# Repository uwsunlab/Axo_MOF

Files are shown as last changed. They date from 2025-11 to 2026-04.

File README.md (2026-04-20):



# Reaction-aware control of autonomous batch synthesis

> **Reaction-aware autonomous batch synthesis for ZIF-67 crystallization using robotic liquid handling, in situ UV–Vis spectroscopy, and adaptive Bayesian optimization**

This repository contains the software, analysis workflows, and supporting assets for **Axo**, a modular autonomous platform for solution-phase batch synthesis. The platform integrates robotic reagent delivery, programmable tool changing, cyclic in situ UV–Vis measurements, kinetic model fitting, and reaction-aware Bayesian optimization to co-optimize **what formulation to test** and **how the experiment should be executed**.

---

## 🌟 Key Features

### Reaction-Aware Adaptive Execution
- **Adaptive scheduling**: 
  - **Throughput-prioritized exploration**: 5-vial batch, 15 min measurement interval
  - **Measurement-prioritized refinement**: 2-vial batch, 5 min measurement interval
- **Reaction-aware trigger**: Switch modes automatically when early reaction progress exceeds a threshold
- **Flexible approval modes**: Manual (interactive) or automatic (fully autonomous)
- **State persistence**: Resume interrupted runs from checkpoints

### Automated Synthesis & Characterization
- **Robotic liquid handling**: Precise dispensing with single/dual syringe systems
- **In situ monitoring**: Cyclic UV–Vis spectroscopy integrated into the batch synthesis workflow
- **Autonomous mixing**: Automated mixing and reaction control
- **Programmable multi-vial workflows**: Batch synthesis and cyclic monitoring across multiple reaction vials

### Intelligent Data Analysis
- **Gualtieri kinetic fitting**: Automated MOF growth curve analysis
- **Reaction-progress extraction**: Automatic extraction of extent of reaction `α(t)` and nucleation rate constant `k_n`
- **Gaussian Process modeling**: Uncertainty-aware surrogate models
- **Expected Improvement**: Efficient exploration-exploitation balance

### Production-Ready Engineering
- **Comprehensive logging**: Experiment metadata, synthesis recipes, operation logs, reference spectra, and time-resolved UV–Vis outputs
- **Error handling**: Graceful handling of excluded or failed fits (`no_reaction`, `no_target_feature`)
- **Hardware safety**: Homing checks, collision avoidance, safe Z movements
- **Configuration management**: JSON-based hardware and experiment configs

---

## 📋 Table of Contents

- [System Architecture](#system-architecture)
- [Installation](#installation)
- [Hardware Requirements](#hardware-requirements)
- [Quick Start](#quick-start)
- [Usage](#usage)
- [Project Structure](#project-structure)
- [Documentation](#documentation)
- [Testing](#testing)

---

## 🏗️ System Architecture

The platform is organized into **four main abstraction layers**:

```
┌─────────────────────────────────────────────────────────────┐
│                    Experiment Layer                         │
│  High-level workflows, BO orchestration, kinetic analysis   │
└─────────────────────────────────────────────────────────────┘
                            ↓
┌─────────────────────────────────────────────────────────────┐
│                  Deck & Labware Layer                       │
│     Spatial management, well positions, volume tracking     │
└─────────────────────────────────────────────────────────────┘
                            ↓
┌─────────────────────────────────────────────────────────────┐
│                      Tool Layer                             │
│   Single Syringe, Dual Syringe, Spectrometer, Gripper       │
└─────────────────────────────────────────────────────────────┘
                            ↓
┌─────────────────────────────────────────────────────────────┐
│                    Machine Layer                            │
│    G-code execution, motion control, hardware interface     │
└─────────────────────────────────────────────────────────────┘
```

**Communication**: HTTP REST API to Duet 3 controller (RepRapFirmware)

---

## 💻 Installation

### Prerequisites

- **Python**: 3.8 or higher
- **Hardware**: Modified Jubilee 3D printer with Duet 3 controller
- **Network**: Local network connection to Jubilee (default: 192.168.1.2)

### Dependencies

Install required Python packages:

```bash
# Core scientific computing
pip install numpy scipy scikit-learn pandas

# Visualization
pip install matplotlib python-ternary

# Optional: Jupyter for notebook interface
pip install jupyter
```

### Setup

1. **Clone the repository**:
   ```bash
   git clone <repository-url>
   cd Axo_MOF
   ```

2. **Install the package** (optional, for development):
   ```bash
   cd Code
   pip install -e .
   ```

3. **Verify installation**:
   ```bash
   python -c "import numpy, scipy, sklearn, matplotlib; print('✓ Dependencies OK')"
   ```

---

## 🔧 Hardware Requirements

### Core Platform
- **Jubilee 3D printer** (modified for lab automation)
- **Duet 3 controller** running RepRapFirmware
- **Network connection** (Ethernet or WiFi)

### Tools (mounted on tool changer)
- **T0**: Single syringe (precise liquid dispensing)
- **T2**: Dual syringe (parallel dispensing)
- **T3**: Ocean Optics spectrometer (UV-Vis, 200-1100 nm)
- **T4**: Vacuum gripper (lid handling)

### Labware
- SLAS-standard microplates (6-slot deck)
- 10-well sample vials (14 mL capacity)
- 2-well precursor reservoirs (60 mL capacity)

---

## 🚀 Quick Start

### Option 1: Command-Line Interface (Recommended for Production)

**optimization with manual approval:**
```bash
cd Code
python run_bo_optimization.py --new --approval-mode manual
```

**Fully autonomous (automatic mode transitions):**
```bash
python run_bo_optimization.py --new --approval-mode automatic
```

**traditional BO:**
```bash
python run_bo_optimization.py --new --phases single --batch-size 5 --max-iterations 20
```

**Resume interrupted run:**
```bash
python run_bo_optimization.py --resume
```

### Option 2: Jupyter Notebook (Recommended for Interactive Use)

```bash
cd Code
jupyter notebook multi_phase_bo_orchestration.ipynb
```

The notebook provides:
- Step-by-step hardware initialization
- Interactive configuration
- In situ monitoring
- Built-in visualization and analysis

---

## 📖 Usage

### Adaptive Execution

The system runs through **two optimization modes**:

| Mode | Goal | Batch Size | Measurement Interval (min) | Exploration (xi) | 
|---|---|---|---|---|
| **Exploration** | Broad screening | 5 | 15 | 0.01 | 
| **Refinement** | Focused optimization | 2 | 5 | 0.01 | 

**Mode Transition Criteria:**
- Switch from exploration to refinement when any sample reaches early reaction progress `α(t1) > 0.5`

### Command-Line Arguments

```bash
python run_bo_optimization.py [OPTIONS]

Required (choose one):
  --new                   Start new optimization
  --resume                Resume from saved state

Multi-Phase Options:
  --approval-mode {manual,automatic}
                          Phase transition approval mode (default: manual)
  --phases {multi,single}
                          Phase configuration (default: multi)

Single-Phase Options (ignored in multi-phase):
  --batch-size N          Experiments per batch (default: 5)
  --max-iterations N      Maximum iterations (default: 20)

General Options:
  --output-dir DIR        Output directory (default: optimization_results)
  --operator NAME         Operator name (default: Operator)
```

### Workflow Example

```bash
# Start new multi-phase optimization with manual approval
python run_bo_optimization.py --new --approval-mode manual --operator "Alice"

# System will:
# 1. Generate 5 initial samples (maximin sampling)
# 2. Prompt you to load vials
# 3. Run automated synthesis + spectroscopy
# 4. Extract kinetic descriptors using Gualtieri fitting
# 5. Update GP model
# 6. Enter exploration phase (5 vials, 15 min interval)
# 7. Prompt for approval when criteria met
# 8. Transition to refinement phase (2 vials, 5 min interval)
# 9. Converge and report optimal conditions
```

### Jupyter Notebook Workflow

See [multi_phase_bo_orchestration.ipynb](Code/multi_phase_bo_orchestration.ipynb) for:
- Interactive hardware setup and calibration
- Configuration with validation
- Progress visualization
- Post-optimization analysis and plotting

---

## 📁 Project Structure

```
Axo_MOF/
├── Code/
│   ├── src/
│   │   └── science_jubilee/
│   │       ├── Machine.py              # Core machine controller
│   │       ├── Experiment.py           # High-level experiment workflows
│   │       ├── tools/                  # Tool implementations
│   │       │   ├── Syringe.py
│   │       │   ├── Double_Syringe.py
│   │       │   ├── Oceandirect_axo.py  # Spectrometer
│   │       │   └── Vacuum_Gripper.py
│   │       ├── labware/                # Labware definitions
│   │       ├── decks/                  # Deck configurations
│   │       ├── analysis/               # Data analysis modules
│   │       │   └── gualtieri.py        # Kinetic fitting
│   │       ├── optimization/           # Bayesian optimization
│   │       │   ├── bayesian.py         # GP modeling, EI
│   │       │   ├── sampling.py         # Initial sampling
│   │       │   ├── phase_config.py     # Phase definitions
│   │       │   ├── phase_manager.py    # Phase transitions
│   │       │   ├── orchestrator.py     # Main BO loop
│   │       │   ├── convergence.py      # Stopping criteria
│   │       │   ├── notifications.py    # User interface
│   │       │   └── logging_config.py   # Structured logging
│   │       └── utils/
│   │           └── synthesis_plan.py   # Experiment plan generation
│   │
│   ├── bayesian.ipynb                  # BO analysis and visualization
│   ├── draft_synthesis_plan.json       # Example synthesis-plan configuration
│   ├── gualtieri.ipynb                 # Kinetic fitting workflow
│   ├── mof_synthesis.ipynb             # Manual synthesis workflows
│   ├── multi_phase_bo_orchestration.ipynb  # Interactive orchestration notebook
│   ├── run_bo_optimization.py          # Main CLI entry point
│   └── sampling.ipynb                  # Initial/maximin sampling workflow
|
├── Dataset/                            # Experimental data
│   └── {experiment_name}_{timestamp}/
│       ├── references/                # Background/reference spectra
│       ├── spectra/                   # Time-resolved spectral outputs
│       ├── experiment_metadata.json   # Experiment-level metadata
│       ├── mof_recipes.json           # Per-vial synthesis recipes
│       └── operations_log.txt         # Chronological robotic execution log
│
└── README.md                           # This file
```

---

## 📚 Documentation

### For Users
- **[Quick Start Notebook](Code/multi_phase_bo_orchestration.ipynb)**: Interactive guide for running experiments

### Example Notebooks
- **[mof_synthesis.ipynb](Code/mof_synthesis.ipynb)**: Manual synthesis workflows and calibration
- **[bayesian.ipynb](Code/bayesian.ipynb)**: BO analysis and visualization
- **[gualtieri.ipynb](Code/gualtieri.ipynb)**: Spectral analysis and kinetic fitting
- **[sampling.ipynb](Code/sampling.ipynb)**: Initial space-filling / maximin sampling
---

## 🧪 Testing

1. **Dry run** (test communication, no synthesis):
   ```bash
   python run_bo_optimization.py --new --phases single --batch-size 1 --max-iterations 1
   # Press Ctrl+C when prompted to load vials
   ```

2. **Single iteration** (full workflow test):
   ```bash
   python run_bo_optimization.py --new --phases single --batch-size 2 --max-iterations 1
   ```

3. **Multi-phase test**:
   ```bash
   python run_bo_optimization.py --new --approval-mode manual
   ```

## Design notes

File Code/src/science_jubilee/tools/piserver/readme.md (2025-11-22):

This is a simple camera server to run on a raspberry pi to basically make a webcam. This lets you ping the pi for a picture when you are ready

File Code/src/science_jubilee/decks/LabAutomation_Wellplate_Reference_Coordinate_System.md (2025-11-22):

# Deck Orientation & Jubilee Coordinate System

 The Laboratory Automation Bed Plate and well plates are oriented as follows:

Lab Automation Bed plate & Wellplate Coordinate System

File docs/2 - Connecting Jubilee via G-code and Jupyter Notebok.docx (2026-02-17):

# Jubilee 3D Documentation (Part 2)

Prepared by: Arthur Chong

Date: 05/20/2025

This document is the second part of a multi-part guide that provides step-by-step instructions on how to connect a Jubilee 3D printer using G-Code and Jupyter Notebook.

## Connecting Jubilee via G-Code

Once the IP address has been successfully configured for the Jubilee, you can connect to it via a web interface that allows G-Code control.

### 1. Accessing the G-Code Web Interface

1. Launch your preferred browser (e.g., Google Chrome). The IP address assigned to Jubilee during setup should be saved in your browser history or bookmarks.
2. Type in the IP address you assigned to the Jubilee during setup.
3. You will be directed to the Duet Web Control interface.

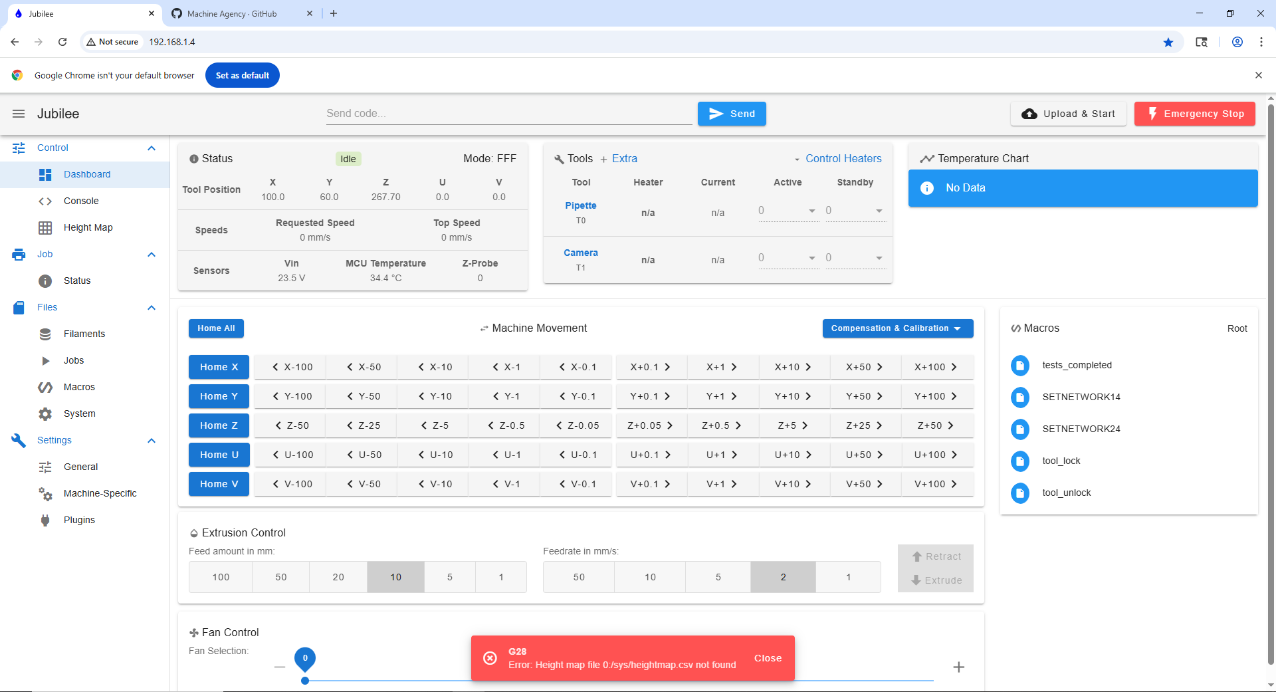
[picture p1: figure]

a

b

c

d

This interface allows you to send G-Code commands directly to the printer, monitor status, control temperatures, move motors, and more.

#### Getting Started Safely

1. Turn on the Jubilee:

Use the external power switch located on the side of the Jubilee frame. (Picture of the switch)

2. Home the Axes:

Before moving the robotic platform, always click "Home All" in the Duet interface to home the X, Y, Z, and U axes.

(U will home first, Y , x , and z)

3. Manual Control:

After homing, you may freely move any of the axes using the interface sliders or input boxes based on your needs.

(Keep in mind of the homing axis)

4. Emergency Stop:

In case of an unexpected issue or malfunction, click the red "Emergency Stop" button in the top-right corner of the screen.

⚠️ This will immediately halt all motion and processes.

u

### 2. Key Interface Components (Figure Description)

a. Side Menu: Access core sections including Jobs, G-Code Files, Machine Control, and Settings.
b. G-Code Console: Send manual commands to operate the printer or test routines.
c. Machine Status Panel: View real-time temperature readings, current axis positions, feed rates, and job status.
d. Motion Control Panel: Move the bed plate and tool holder by manually changing the X, Y, Z, and U axis positions.

### 3. Side Menu – File Options Overview (Additional Information)

Within the side menu of the Duet Web Control interface, the "Files" section is divided into several important tabs:

##### 1. Jobs

- Contains G-code files that can be executed as print or automation jobs.
- You can upload, delete, or organize files for direct execution on the machine.
- Pre-made Job Templates Science Jubilee provides a collection of pre-configured G-code templates used for:
  - Tool pickup
  - Tool change

These templates are useful starting points for setting up your own automated workflows.
👉 Science Jubilee G-code Templates (GitHub) (https://github.com/machineagency/science-jubilee/tree/main/src/science_jubilee/calibration/templates)

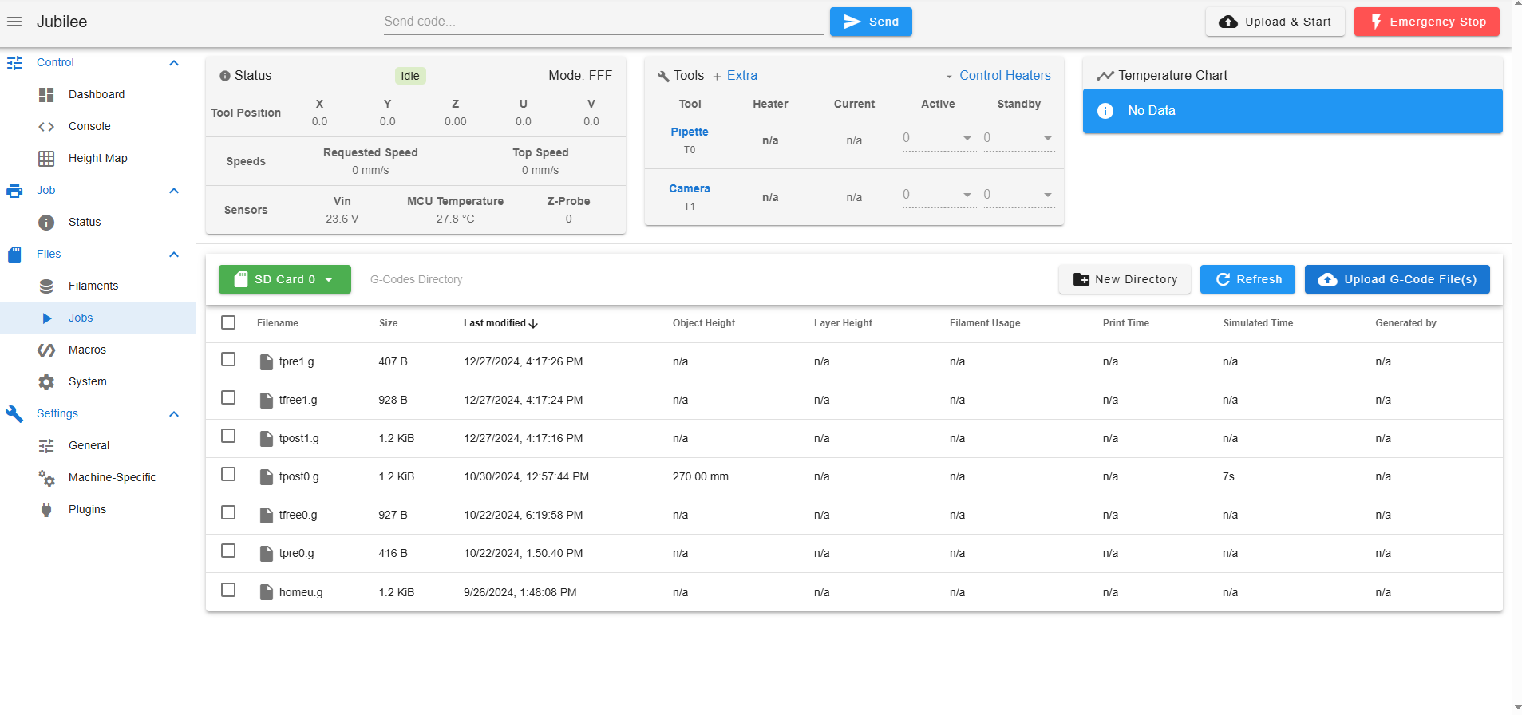
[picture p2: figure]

##### 2. Macros

- Stores reusable G-code scripts for common tasks (e.g., tool lock, tool unlocking).
- Useful for automating frequent commands or procedures.
- Pre-configured Macro Files The Machine Agency has provided a collection of. g macro files specifically designed for Jubilee with Duet 3. 👉 Duet3 Macros – Jubilee GitHub Repository (https://github.com/machineagency/jubilee/tree/main/software/duet_config_files/duet3/macros)

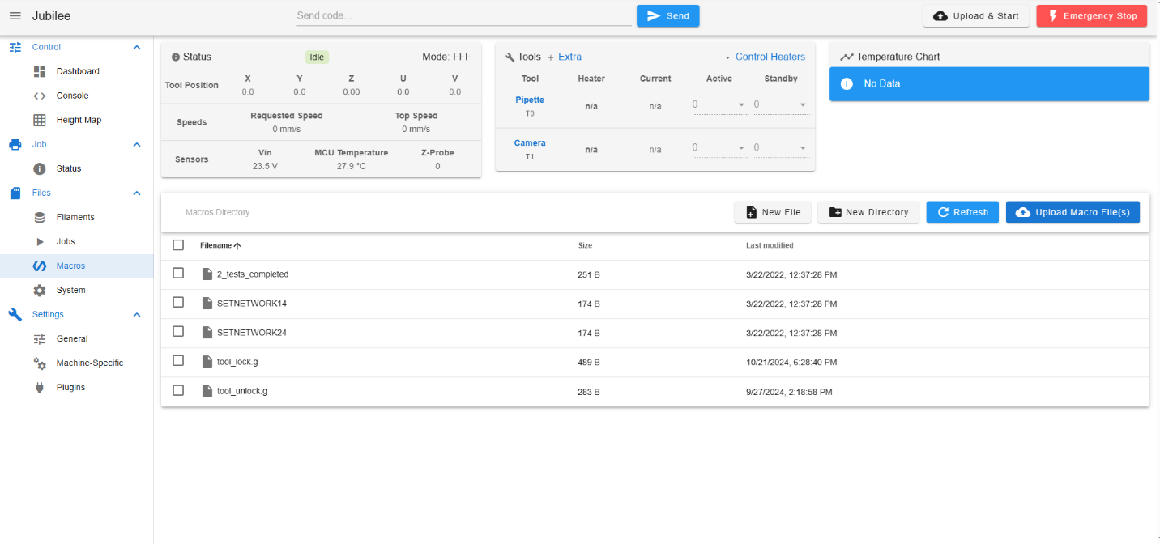
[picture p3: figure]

##### 3. System

- Holds configuration files such as:
  - config.g (main printer configuration)
  - Homex.g, homey.g, homez.g, etc. – Homing sequences for each axis.
- Changes to these files affect machine behavior and should be edited carefully based on your system.

⚠️ Note: Any changes to these files directly affect how the Jubilee operates. Be sure to back up the original files and test carefully after making modifications.

- Reference Configuration Files The Machine Agency provides a complete set of example configuration files for a Duet 3-based Jubilee setup. These can be used as a baseline and tailored to your lab’s hardware.

👉 System Config Files – Duet3 (Jubilee GitHub) (https://github.com/machineagency/jubilee/tree/main/software/duet_config_files/duet3/sys)

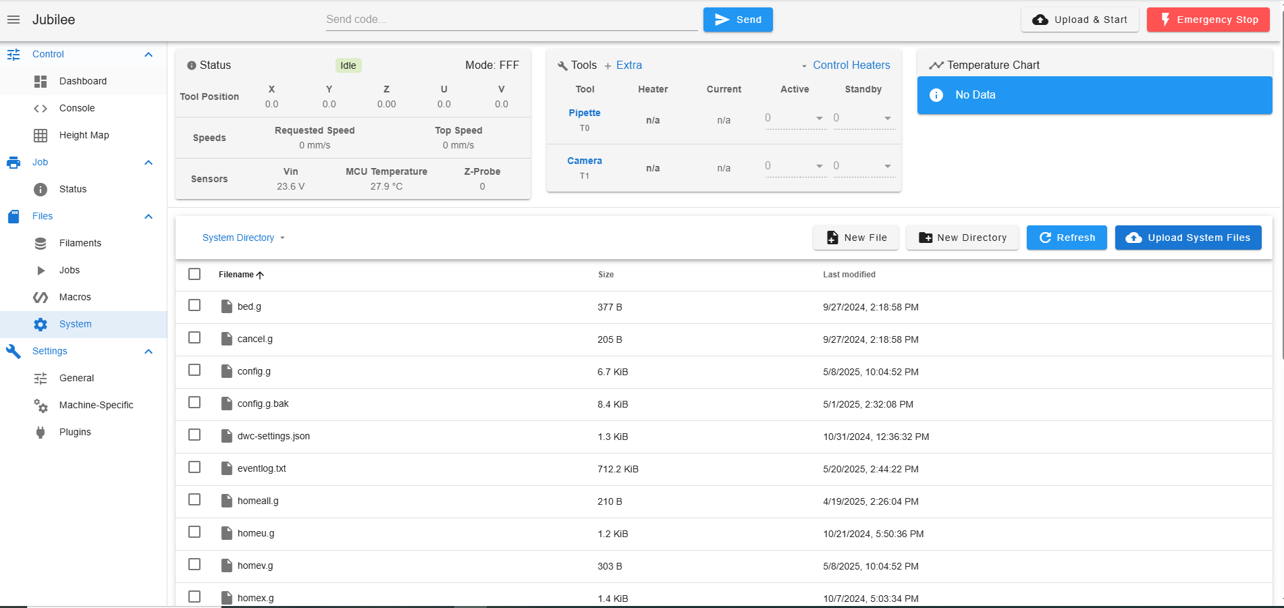
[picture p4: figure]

##### 4. Machine-Specific

- Displays information specific to the hardware setup.
- Here you can view:
  - The type of Duet board in use (e.g., Duet 3 Mini, Duet 2 WiFi)
  - Firmware version and connected expansion boards

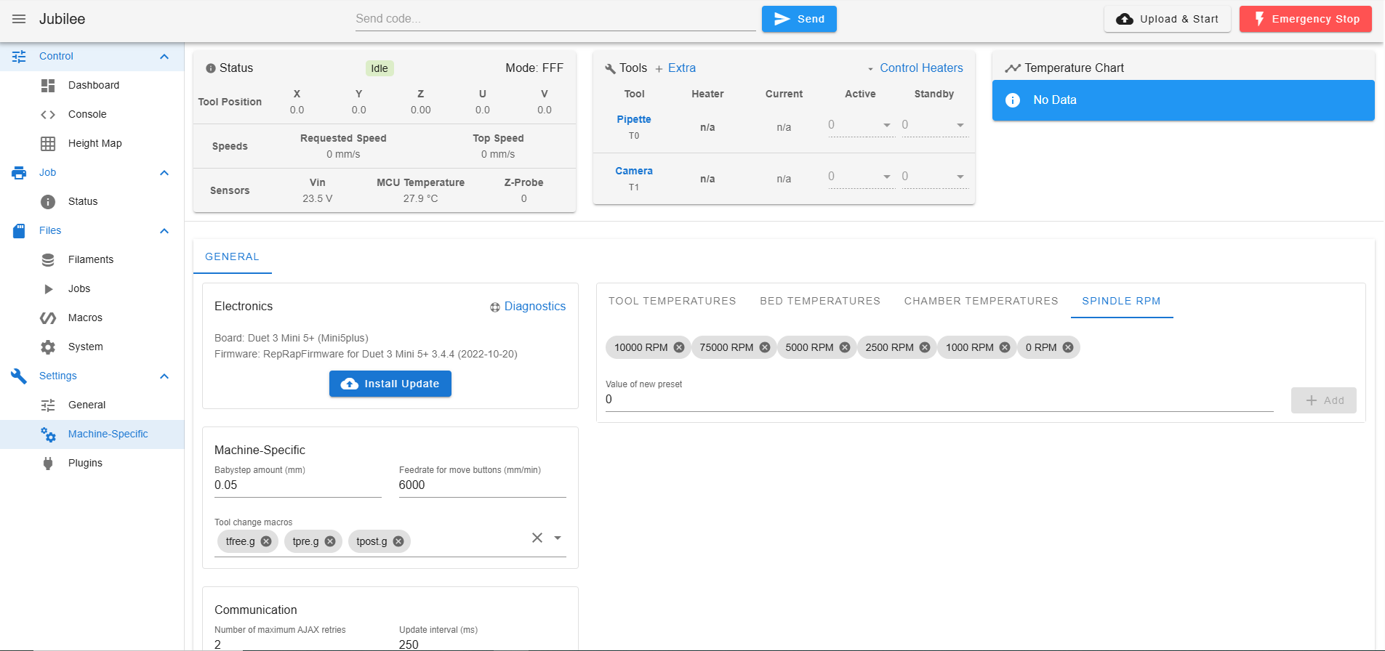
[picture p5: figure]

#### 📚 Additional Resources

To learn more about G-Code and how it's used in Jubilee, refer to the following documentation:
🔗 G-Code Primer
👉 https://science-jubilee.readthedocs.io/en/latest/getting_started/primer.html

For provisioning the board and initial connection setup:
🔗 New User Guide
👉 https://science-jubilee.readthedocs.io/en/latest/getting_started/new_user_guide.html

Duet3D also provides an excellent guide on connecting to your Duet board:
🔗 Duet3D – Getting Connected
👉 https://docs.duet3d.com/How_to_guides/Getting_connected/Getting_connected_to_your_Duet

Senbd code

Config gile change – tool manupulation

## Automating Jubilee with Jupyter Notebook

After uploading all the necessary files into the Macros and System folders, users can connect to Jubilee programmatically using Jupyter Notebooks. This enables full automation of experiments and workflows.

Through Jupyter, users can:

- Send G-code commands via Python
- Control tool pickup and change sequences
- Coordinate movement and actions on the Lab Automation Deck
- Run complex experimental protocols with real-time feedback

### 1. Getting Started Resources

To begin using Jubilee with Jupyter Notebooks, refer to the following tutorials:

1. 👉 Intro to the Machine Driver (https://science-jubilee.readthedocs.io/en/latest/getting_started/machine_intro.html) Learn about the software stack behind Jubilee automation.
2. 👉 Lab Automation Deck Guide (https://science-jubilee.readthedocs.io/en/latest/getting_started/deck_guide.html) Understand how the deck is structured and how to control lab hardware in a programmable way.

### 2. API Reference

The Science Jubilee project provides a fully documented API that outlines the available functions and classes used to interact with and automate the Jubilee 3D printer.

Official API Documentation:
👉 Science Jubilee AutoAPI Reference (https://science-jubilee.readthedocs.io/en/latest/autoapi/index.html)

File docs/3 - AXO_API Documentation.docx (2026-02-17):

AXO API Documentation

System Overview

The AXO platform integrates four modular tools within a 3D printer–like motion framework through a unified control architecture:

- Dual Syringe Pump
- Spectrometer
- Vacuum Gripper
- Single Syringe Pump (or OT2 Pipettes, adapted from the Science-Jubilee project (https://jubilee3d.com/index.php?title=10cc_Syringe_Tool))

Architecture

Each module interfaces through an independent control layer coordinated via:

- G-code: The primary command language governing AXO hardware motion and tool operations.
- JSON Configuration Files: Define labware mappings, tool parameters, and system initialization settings.
- Python Interface: Serves as the orchestration layer, interpreting G-code, managing configurations, and coordinating inter-tool operations.

Table of Contents

## Wiring Diagram

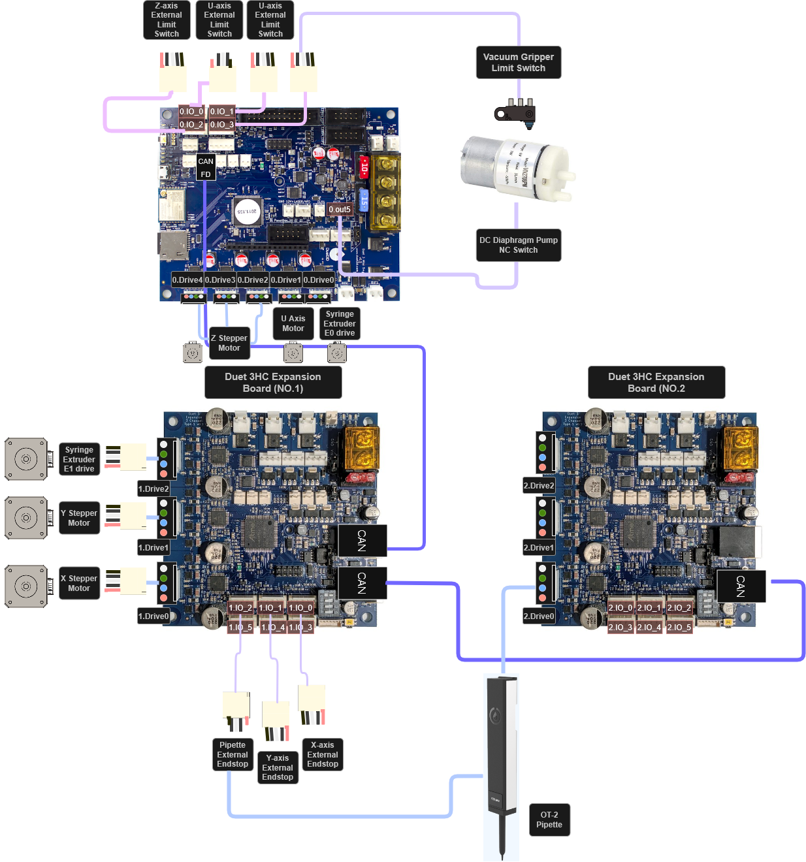
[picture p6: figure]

Note : There is no need to explicitly follow this wiring diagram.

## Dual Syringe Pump

Note: The Dual Syringe Pump API is adapted from the original SyringeExtruder.py provided by the Jubilee collaborators (https://science-jubilee.readthedocs.io/en/latest/building/syringe_tool.html). However, our implementation introduces significant modifications, including automatic refill and aspiration routines. These enhancements eliminate redundant motions and remove the need for tool-changing mechanisms, optimizing the system specifically for materials synthesis workflows.

### Dual Syringe Pump config.g Setup

To configure the Dual Syringe Pump, add the following lines to the config.g file located in the Jubilee/src directory:

—-----------------------------------------------------------------------------------------------------------------

; Dual Syringe Pump Configuration

M584 E0.0:1.2 R0 S1

M569 P1.2 S1 ; Syringe Motor direction (for E1, expansion board)

M569 P0.0 S1 ; Syringe Pump Motor direction (for E0, mainboard)

M906 E{0.85*sqrt(2)*1400}:{0.85*sqrt(2)*1400} ; Syringe Pump: 85% of 1400mA RMS for both E0 and E1

M350 E16:16 I1 ; Enable 16x microstepping for both extruder drives (E0 and E1)

M92 E3200:3200 ; Steps/mm for both drives (E0, E1) of the Double Syringe Pump

M201 E1000:1000 ; Acceleration for both extruder drives (E0, E1)

M203 E1000:1000 ; Maximum speeds for both extruder drives (E0, E1)

M566 E500:500 ; Jerk settings for both extruder drives (E0, E1)

M563 P2 S"Syringe_Pump_r" D0:1 ; Tool 2: Syringe Pump using drives 0 and 1 (E0 and E1)

—--------------------------------------------------------------------------------------------------------------------

### Dual Syringe Pump API (Double_Syringe.py)

### Initialization & Configuration

#### __init__(...)

- Initializes the DoubleSyringe object, sets up tool metadata (like plunger range, conversion factor mm_to_ml), and loads the syringe config from a JSON file.

#### load_config(config: str)

- Loads parameters like min_range, max_range, and mm_to_ml from a config file in /tools/configs.
- Verifies that all required fields are present.

#### post_load()

- Queries the firmware for the tool’s extruder (E) assignments and stores them as self.e0_drive and self.e1_drive (e.g., "E0", "E1").
- Must be called after the tool is loaded into the machine.

#### check_bounds(pos)

- Verifies that a target plunger position pos is within physical limits.
- Throws ToolStateError if movement is unsafe.

### Helper Function for Syringe Motions

In the Dual Syringe Pump, we do not use direct dispensing commands. Instead, the system is designed to automatically refill both syringes by driving them to the end of their respective coordinate ranges.

#### _aspirate(vol, drive, s)

- Moves the specified syringe backwards to aspirate a given volume.
- Checks for overfilling and clamps if needed.
- Returns the actual aspirated volume.
- S : FeedRate (Speed of the motors)

#### _refill(drive, s)

- Moves the plunger to the max position (full) for the given drive, as a full refill.
- Only handles plunger motion—not well positioning.

#### _plunger(drive, delta_mm, s)

- Performs a plunger movement (positive or negative) by a specified distance in relative extrusion mode.
- Switches between relative (M83) and absolute (M82) modes as needed.

### Basic High-Level Syringe Commands

#### refill(drive, refill_loc, s)

- Moves the tool to the refill location and performs a full refill using _refill.

#### aspirate(vol, location, s)

- Moves the tool to a well and aspirates a given volume.
- Uses _aspirate after moving to the coordinates.

#### dispense(vol, location, s)

- Moves the tool to a well and dispenses a given volume.
- Uses _dispense (which seems missing in the code and replaced by _move_channel).

### Drive-Specific Coordinate Helpers

#### _xy_for_drive(drive, loc)

- If the drive is E0, adds offset_x to the x-coordinate. (You can switch your drive on your choice but offsets between the needles should be calculated from the center of each syringe pump)
- Ensures the right(or left) syringe dispenses at the correct x-shifted location.

### Unified Aspirate/Dispense Handler

#### _move_channel(drive, loc, vol, s, dispense, refill_loc)

- Core handler for both aspirate and dispense:
  - Calculates required travel.
  - Handles overfill (for aspirate) or underflow (for dispense) with auto-refill.
  - Moves to correct position and performs plunger motion.
  - Returns volume moved in mL.
- Uses _xy_for_drive() to account for offset_x.

### Wrappers for Dual Channels

To simplify high-level control, the following wrapper functions abstract the direct calls to _move_channel(). These wrappers are designed for clean and readable usage in automation scripts and protocols.

#### aspirate_e0(vol, refill_loc_e, s)

- Aspirates using the E0 drive.

#### dispense_e0(vol, sample_loc_e, refill_loc_e, s)

- Dispenses using E0, with auto-refill if needed.

#### aspirate_e1(vol, refill_loc_v, s)

- Aspirates using E1.

#### dispense_e1(vol, sample_loc_v, refill_loc_v, s)

- Dispenses using E1, with auto-refill if needed.

### Reset Plungers to Zero

#### reset_position(s)

- Moves both syringes to position 0 (fully dispensed)
- Useful to initialize or finalize a run.
- No axis mapping in Syringe Pump, better to reset to position 0.

## Spectrometer

Note: For AXO, the Spectrometer API is built on the proprietary OceanDirect SDK provided by Ocean Optics and serves as a central controller that orchestrates the spectrometer’s interaction with other hardware components. It directly interfaces with the OceanDirect API for real-time spectral acquisition while coordinating machine motion through machine.py and precise well positioning via labware.py. This integration enables synchronized control across devices, allowing the spectrometer to trigger or respond to robotic actions dynamically. Additionally, the API supports flexible data processing routines, making it well-suited for automated, multi-well material characterization workflows.

### Spectrometer config.g Setup

To configure the Spectrometer within the AXO system, add the following line to the config.g file located in the Jubilee/src directory:

—-----------------------------------------------------------------------------------------------------------------

M563 P3 S"Spectrometer"

—--------------------------------------------------------------------------------------------------------------------

### Spectrometer API (Oceandirect_axo.py)

### Initialization & Setup

#### __init__(...)

- Initializes the spectrometer tool, directory structure, and reference spectra.
- Calls open_spectrometer() and _load_references() to auto-connect and recover white/dark spectra.
- Creates:
  - base_dir: root folder for saving data (e.g., "Spectra/")
  - plate_dir: session folder (e.g., "Spectra/20250601/")
  - ref_dir: folder to store dark/white references

### Device Management

#### find_spectrometers()

- Scans for connected Ocean Insight spectrometers.
- Returns a list of available device IDs.

#### open_spectrometer()

- Opens the first available spectrometer and returns it.
- Saves the spectrometer and device ID to self.spectrometer and self.device_id.

#### close_spectrometer()

- Closes the active spectrometer connection cleanly.

### Configuration

#### configure_device(integration_time_us, scans_to_avg, boxcar_width)

- Sets integration time (exposure), scan averaging, and boxcar width (smoothing).

#### lamp_shutter(open)

- Opens/closes the internal shutter, if supported by the spectrometer hardware.

### Measurement & Processing

#### measure_raw_spectrum()

- Returns (wavelengths, intensities) as NumPy arrays.

#### compute_absorbance(sample_vals, dark_vals, white_vals, eps, clip)

- Computes absorbance spectrum from raw data:

A(λ) = -log_10 ((I_(sample) -I_(dark))/(I_(white) -I_(dark) +ε))

- Adds eps to avoid division by zero and optionally clips values.

### Measurement Workflow

#### position_probe(location)

- Moves the stage above the specified well location using Labware._getxyz().
- Saves the current well and location for downstream reference.

#### collect_spectrum(location, elapsed_min, open, save)

- Core function for acquiring a spectrum:
  1. Positions the probe
  2. Opens/closes shutter if needed
  3. Measures raw spectrum
  4. Converts to absorbance
  5. Saves to CSV (if save=True) with time-stamped metadata

### Reference Spectra Handling

Once a reference spectrum has been collected, it can be reused in subsequent measurements to ensure consistent calibration and comparison. The system automatically stores reference spectra in the base_dir/ref directory. You can load and apply a previously captured reference by calling it from this path, eliminating the need to re-capture reference data for every session.

#### set_dark(n_avg)

- Averages n_avg dark readings and stores in ref_dir with a timestamped filename (e.g. dark_20250601_112300.npy).

#### set_white(n_avg)

- Same as above, but for white reference.

#### _load_references()

- Tries to load the most recent timestamped dark_* and white_* files.
- Falls back to dark.npy / white.npy if newer refs not found.

#### _latest_ref(prefix)

- Utility that returns the most recent reference file path based on prefix ("dark" or "white").

### Storage and Metadata

#### set_storage_root(new_root)

- Changes all directory roots to a new base (e.g., switching between experiments).

#### _csv_path(well_id)

- Returns a path like Spectra/20250601/A1.csv.

#### _ensure_file(path, meta)

- Creates the file with a YAML-style metadata header if it doesn't exist.

#### _append_spectrum_csv(well_id, time_min, wl, absorbance, meta)

- Appends a new absorbance column to a .csv file for the specified well, with time (<time_min> min) as column label.
- Preserves YAML-style metadata in the header.

#### read_spectrum_csv(path)

- Reads a saved .csv file and returns both metadata and absorbance DataFrame.

### Global Utility Functions

#### _yaml_header(meta)

- Formats metadata dictionary as a block comment header in YAML-style (for readability and parsing).

#### _parse_header(path)

- Parses and returns the header block as a dictionary + number of lines used.

## Vacuum Gripper

Note: Vacuum Gripper leverages both hardware-level G-code execution and Python-based software abstraction for automated pick-and-place workflows. We implemented the control logic for a vacuum-powered gripping tool. It combines movement planning, GPIO vacuum control, and contact-based probing.

In order to use the Vacuum Gripper you need an NC or NO limit switch and pin it through DUET3D, or else you need to hardcode the picking z-location for appropriate contact.

*To use multiple z-probe, firmware should be updated to 3.5>

*Firmware mismatch of Mainboard(Duet3D mini 5+, Duet3D expansion 3HC) causes improper I/O pin behavior or failure.

### Vacuum Gripper Config.g Setup

To configure the Vacuum Gripper for use with the Duet3D Expansion 3HC board, add the following lines to your config.g file located in the Jubilee/src directory:

—-----------------------------------------------------------------------------------------------------------------

M558 K2 P8 C"^1.io3.in" ; Expansion Board 3HC board number 1 at io3 port, in & ground.

;"Control Point" ; Offset it downwards slightly so we don't smear it along

; the bed while traveling when z=0.

G31 K2 P100 X0 Y0 Z-vacuum_gripper_offsets ; Set the limit switch as the

M563 P4 S"Vacuum_Gripper" ; Define Tool 4 named "Vacuum_Gripper"

—--------------------------------------------------------------------------------------------------------------------

### Vacuum Gripper API

### Initialization

#### __init__(index, name, vacuum_pin, limit_switch_pin)

- Initializes the gripper, storing:
  - vacuum_pin for PWM control (e.g., Duet's M42 P<vacuum_pin> S<pwm>) PWM is the drive voltage to the pump.
  - limit_switch_pin for Z-probe trigger (e.g., Duet's G30 K<switch>)
- Throws error if either pin is not provided

#### grip(location, pwm, retract_z_after_probe)

- Pick up an object at a given location:
  1. Moves in Z safely
  2. Moves to x, y
  3. Starts vacuum (M42 P... S<pwm>)
  4. Lowers Z until limit switch (Z-probe) is triggered via G30 K<switch> S-1
  5. Optionally retracts Z after probing

S-1 means probe but don’t update the Z offset, keeping bed leveling safe

#### drop(location, retract_z_after_probe)

- Release object at a target location:
  1. Moves safely in Z
  2. Moves to x, y
  3. Triggers Z-probe for contact release
  4. Stops vacuum (M42 P... S0)

#### _probe_limit_switch(retract_z_after_probe)

- Sends G-code:
  - G30 K<limit_switch_pin> S-1 to probe Z until the limit switch is triggered
  - move(dz=...) to retract Z afterward

#### pick_and_place(grip, drop, pwm, retract_z_after_probe)

- High-level macro
  1. Calls grip() at the pickup location
  2. Moves to drop() location
  3. Finishes with safe Z retraction

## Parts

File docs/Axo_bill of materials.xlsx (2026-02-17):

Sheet: BOM
Bill of Materials, Axo
Hardware | Axo base
 | Item | Unit price | Quantity | Total | Link
 | Jubilee Motion Platform Kit | $1799.99 | 1 | $1799.99 | https://www.filastruder.com/collections/jubilee/products/jubilee-motion-platform-kit
 | Limit Switches | $1.14 | 5 | $5.70 | https://www.digikey.com/en/products/detail/e-switch/SS0750300F070P1A/3778167
 | 2x5 Female IDC Socket Connector | $6.90 | 1 | $6.90 | https://www.amazon.com/dp/B07W5C4P6Z?skipTwisterOG=2
 | Grey Flat Ribbon Cable In Roll | $9.97 | 1 | $9.97 | https://www.amazon.com/dp/B08435GF42?skipTwisterOG=2
 | M3 Hex Bolt Screw & Flat Head Hex Socket Screws | $11.91 | 1 | $11.91 | https://www.amazon.com/dp/B076ZDXK1W?skipTwisterOG=2
 | Heat Set Insert Tool Kit | $8.99 | 1 | $8.99 | https://www.filastruder.com/products/heat-set-insert-tool-kit?variant=40437399519303
 | Tool Balls for Jubilee (3-pack) | $2.99 | 5 | $14.95 | https://www.filastruder.com/products/tool-balls-for-jubilee-3-pack?_pos=1&_sid=67e00ff4a&_ss=r
 | Wedge Plate for Jubilee (3-pack) | $1.99 | 5 | $9.95 | https://www.filastruder.com/products/wedge-plate-for-jubilee?_pos=2&_sid=67e00ff4a&_ss=r
 | Large Zip Ties | $21.99 | 1 | $21.99 | https://www.amazon.com/dp/B0BZ12PGRT?skipTwisterOG=2
 | Jubilee Aluminum Z Yokes by Mandala Rose Works | $89.99 | 1 | $89.99 | https://www.filastruder.com/collections/jubilee/products/jubilee-aluminum-z-yokes-by-mandala-rose-works
 | Raspberry Pi 5 8GB / Vilros Complete Kit | $159.99 | 1 | $159.99 | https://vilros.com/products/raspberry-pi-5?variant=40082990399582
 | 26 Pins Standard 0.1" 2.54mm Female Sockets | $13.55 | 1 | $13.55 | https://www.amazon.com/dp/B00DR9J5E8?skipTwisterOG=2
 | 40 Pins Standard 0.1" 2.54mm Sockets | $12.85 | 1 | $12.85 | https://www.amazon.com/dp/B00K2NTSJE?skipTwisterOG=2
 | 26 Pins Connector Flat Ribbon Cable | $9.99 | 1 | $9.99 | https://www.amazon.com/dp/B07JPZ9YCF?skipTwisterOG=2
 | 5M GT2 Timing Belt | $10.99 | 1 | $10.99 | https://www.amazon.com/dp/B08R93QQ8Z?skipTwisterOG=2
 | 360 Pcs Allen Head Screws | $7.58 | 1 | $7.58 | https://www.amazon.com/360-Pcs-Allen-Head-Screws/dp/B0D9DCKCNM
 | Socket Head Cap Bolts Screws and Nuts Kit | $11.99 | 1 | $11.99 | https://www.amazon.com/DYWISHKEY-Pieces-Stainless-Socket-Screws/dp/B07VPGQ1RZ?s=industrial
 | M3 spacer (OD 7mm ID 3.2mm) | $9.99 | 1 | $9.99 | https://www.amazon.com/MCMASKE-Plastic-Unthreaded-Assortment-Clearance/dp/B0B7P1JWGT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
 | Total |  |  | $2207.28
Hardware | Tool - Single Syringe
 | Item | Unit price | Quantity | Total | Link
 | Air-Tite™ Sterile Syringes 10 mL, Luer Lock (pack of 100) | $29.70 | 1 | $29.70 | https://www.fishersci.com/shop/products/sterile-syringes-48/14817178
 | BD Hypodermic Needles 23 G, 1.5 in., 0.025 in., Thin (pack of 100) | $27.50 | 1 | $27.50 | https://www.fishersci.com/shop/products/bd-general-use-precisionglide-hypodermic-needles-20/148266C
 | Tr8x2 Lead Screw with T8 Brass Nut | $11.99 | 1 | $11.99 | https://www.amazon.com/150mm%EF%BC%885-9-Inches%EF%BC%89Tr8x2-Thread-Printer-Machine/dp/B0B8RGRYNW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
 | Wedge Plate for Jubilee | $1.99 | 1 | $1.99 | https://www.filastruder.com/products/wedge-plate-for-jubilee?_pos=2&_sid=67e00ff4a&_ss=r
 | GT Timing Belt Pulley | $7.59 | 1 | $7.59 | https://www.amazon.com/gp/product/B07K6BRL4K?th=1
 | 200mm MGN9 Linear Sliding Rail Guide | $16.59 | 1 | $16.59 | https://www.amazon.com/gp/product/B08HYFM5BP
 | 8mm Nonmarring Clamp Collar | $11.99 | 1 | $11.99 | https://www.amazon.com/Shaft-Collar-Aluminum-Thickness-Screws/dp/B0BNZ937MV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
 | Thrust Bearing 8mm Bore | $9.99 | 1 | $9.99 | https://www.amazon.com/HiPicco-Bearings-F8-16M-Miniature-Direction/dp/B0BXY9VF8X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
 | LDO Slim Power Extruder Stepper Pancake Motor | $15.95 | 1 | $15.95 | https://kb-3d.com/store/stepper-motors-servos/66-ldo-slim-power-extruder-stepper-pancake-motor-42sth25-1404mac-1644693835267.html
 | Stepper Motor Heatsink | $6.99 | 1 | $6.99 | https://www.amazon.com/Easycargo-40x40x11mm-Conductive-Thermoelectric-40mmx40mmx11mm/dp/B07D4FVC61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
 | 110t 2gt Belt | $9.89 | 1 | $9.89 | https://www.amazon.com/uxcell-Timing-Closed-110-2GT-6-Printer/dp/B0CN9H34K9
 | Total |  |  | $150.17
Hardware | Tool - Dual Syringe
 | Item | Unit price | Quantity | Total | Link
 | Air-Tite™ Sterile Syringes 10 mL, Luer Lock (pack of 100) | $29.70 | 1 | $29.70 | https://www.fishersci.com/shop/products/sterile-syringes-48/14817178
 | BD Hypodermic Needles 23 G, 1.5 in., 0.025 in., Thin (pack of 100) | $27.50 | 1 | $27.50 | https://www.fishersci.com/shop/products/bd-general-use-precisionglide-hypodermic-needles-20/148266C
 | Tr8x2 Lead Screw with T8 Brass Nut | $11.99 | 1 | $11.99 | https://www.amazon.com/150mm%EF%BC%885-9-Inches%EF%BC%89Tr8x2-Thread-Printer-Machine/dp/B0B8RGRYNW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
 | Wedge Plate for Jubilee | $1.99 | 2 | $3.98 | https://www.filastruder.com/products/wedge-plate-for-jubilee?_pos=2&_sid=67e00ff4a&_ss=r
 | 200mm MGN9 Linear Sliding Rail Guide | $16.59 | 2 | $33.18 | https://www.amazon.com/gp/product/B08HYFM5BP
 | 8mm Nonmarring Clamp Collar | $11.99 | 1 | $11.99 | https://www.amazon.com/Shaft-Collar-Aluminum-Thickness-Screws/dp/B0BNZ937MV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
 | Thrust Bearing 8mm Bore | $9.99 | 1 | $9.99 | https://www.amazon.com/HiPicco-Bearings-F8-16M-Miniature-Direction/dp/B0BXY9VF8X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
 | LDO Slim Power Extruder Stepper Pancake Motor | $15.95 | 1 | $15.95 | https://kb-3d.com/store/stepper-motors-servos/66-ldo-slim-power-extruder-stepper-pancake-motor-42sth25-1404mac-1644693835267.html
 | Stepper Motor Heatsink | $6.99 | 1 | $6.99 | https://www.amazon.com/Easycargo-40x40x11mm-Conductive-Thermoelectric-40mmx40mmx11mm/dp/B07D4FVC61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
 | 16-T 2GT Drive Pulley for 6mm Belt | $6.99 | 1 | $6.99 | https://www.amazon.com/WINSINN-Aluminum-Synchronous-Timing-Printer/dp/B077GMR328
 | 110T, 2GT Timing Belt 6mm Tall | $9.99 | 1 | $9.99 | https://www.amazon.com/PAGOW-Printer-Timing-Closed-Rubber/dp/B088M3V865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
 | 2GT 40T Pulley 8B | $12.99 | 1 | $12.99 | https://a.co/d/4UQ8Md9
 | 110t 2gt Belt | $9.89 | 1 | $9.89 | https://www.amazon.com/uxcell-Timing-Closed-110-2GT-6-Printer/dp/B0CN9H34K9
 | Wire Extender 4pin for LDO Motors | $7.99 | 1 | $7.99 | https://www.amazon.com/Printer-Stepper-Motor-Connector-HX2-54/dp/B0CRDXNWMZ?sp_csd=d2lkZ2V0TmFtZT1zcF9tdGY
 | Total |  |  | $199.12
Hardware | Tool - Vacuum Gripper
 | Item | Unit price | Quantity | Total | Link
 | Vacuum 12V DC Pump | $9.97 | 2 | $19.94 | https://www.amazon.com/dp/B07FGFPKNS?s=hi&sp_csd=d2lkZ2V0TmFtZT1zcF9kZXRhaWxfdGhlbWF0aWM
 | Hose Balbs 3/16" to 1/8" | $6.99 | 1 | $6.99 | https://www.amazon.com/Boeray-5pcs-Brass-Fitting-Adapter/dp/B07DVFG5V5
 | 1/8" Hose Barb Fitting Equal Barbed Y Shaped | $7.99 | 1 | $7.99 | https://www.amazon.com/ANPTGHT-Fitting-plastic-Splicer-Household/dp/B08S6T79JD?sp_csd=d2lkZ2V0TmFtZT1zcF9hdGY
 | Vacuum Suction Cup | $13.99 | 2 | $27.98 | https://www.amazon.com/dp/B0BRKHGQQ5?s=industrial&sp_csd=d2lkZ2V0TmFtZT1zcF9kZXRhaWw
 | 1/8" Silicone Hose 10feet | $8.99 | 1 | $8.99 | https://www.amazon.com/Silicon-CellarBrew-Silicone-Brewing-Winemaking/dp/B08RYFKD53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
 | Wedge Plate for Jubilee | $1.99 | 1 | $1.99 | https://www.filastruder.com/products/wedge-plate-for-jubilee?_pos=2&_sid=67e00ff4a&_ss=r
 | LDO Slim Power Extruder Stepper Pancake Motor | $15.95 | 1 | $15.95 | https://kb-3d.com/store/stepper-motors-servos/66-ldo-slim-power-extruder-stepper-pancake-motor-42sth25-1404mac-1644693835267.html
 | Total |  |  | $71.89
Hardware | Tool - Spectrometer
 | Item | Unit price | Quantity | Total | Link
 | Ocean-HDX UV to NIR Optimized Spectrometer | $7369.00 | 1 | $7369.00 | https://www.oceanoptics.com/spectrometer/ocean-hdx/
 | Tungsten Halogen Light Source HL-2000-LL | $1804.05 | 1 | $1804.05 | https://www.oceanoptics.com/accessories/light-sources/light-sources-product-insight/
 | 300-micron Transmission Dip Probe, UV, PEEK Sleeve | $1214.00 | 1 | $1214.00 | https://www.oceanoptics.com/accessories/fibers-and-probes/transmission-dip-probes/
 | Adjustable Path (2-10 mm) PEEK Tip for TP300-UV/VIS | $392.00 | 1 | $392.00 | https://www.oceanoptics.com/accessories/fibers-and-probes/transmission-dip-probes/
 | Wedge Plate for Jubilee | $1.99 | 1 | $1.99 | https://www.filastruder.com/products/wedge-plate-for-jubilee?_pos=2&_sid=67e00ff4a&_ss=r
 | Total |  |  | $10779.05
 | Chemicals and Labwares
 | Item | Unit price | Quantity | Total | Link
 | Cobalt(II) nitrate hexahydrate, 99%, Thermo Scientific Chemicals | $64.65 | 1 | $64.65 | https://www.fishersci.com/shop/products/cobalt-ii-nitrate-hexahydrate-99-pure-thermo-scientific/AC213091000
 | 2-Methylimidazole, 99%, Thermo Scientific Chemicals | $40.50 | 1 | $40.50 | https://www.fishersci.com/shop/products/2-methylimidazole-99-thermo-scientific/AC127001000
 | Methanol, 4 Liter, HPLC, Thermo Scientific Chemicals | $26.70 | 1 | $26.70 | From Research Stockroom
 | Fisherbrand Glass Shell Vials, 11 mL, pack of 144 | $133.20 | 1 | $133.20 | https://www.fishersci.com/shop/products/51-expansion-short-style-glass-shell-vials-without-closures/0333930F
 | Bottle, Specimen 2 Oz Glass WM | $3.58 | 4 | $14.32 | From Research Stockroom
 | Total |  |  | $279.37

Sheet: Summary
Category |  | Cost (USD)
Axo base |  | 2207
Synthesis | Single syringe | 150
 | Dual syringe | 199
 | Vacuum gripper | 72
Characterization | Spectrometer | 10779
Total |  | 13407

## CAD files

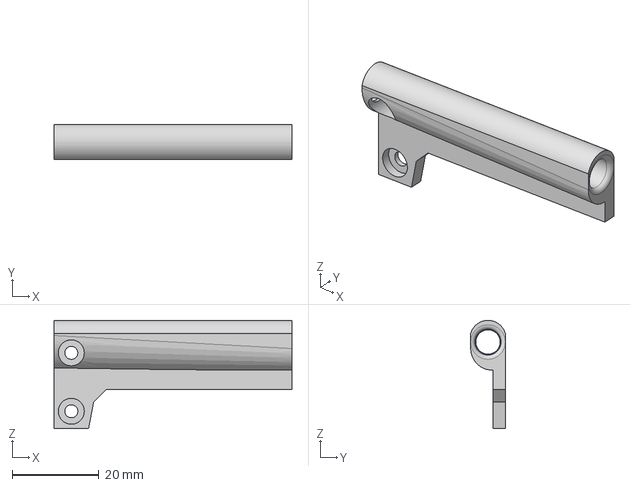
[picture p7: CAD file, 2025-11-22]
CAD/Dual_Syringe/parkin_wing_right v2.step
55.0 x 8.00 x 25.0 mm

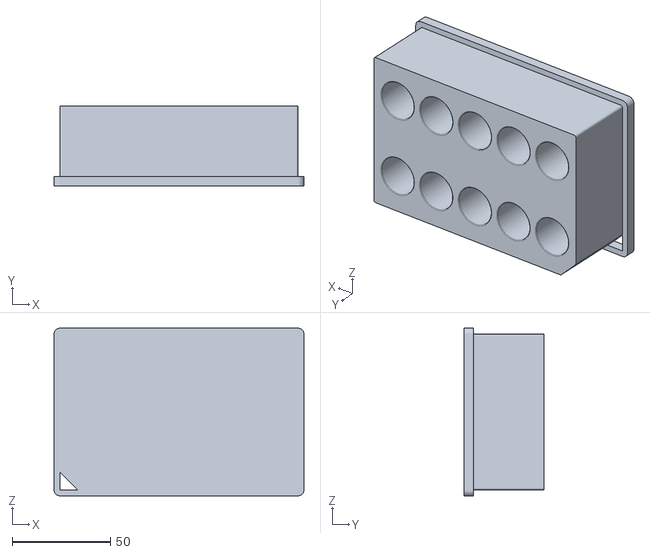
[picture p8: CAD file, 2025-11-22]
CAD/Labwares/UWSUNLAB_10WELLPLATE_11ML_RESERVOIR_INSERT_KIT v2.stl
127.5 x 41.0 x 85.5

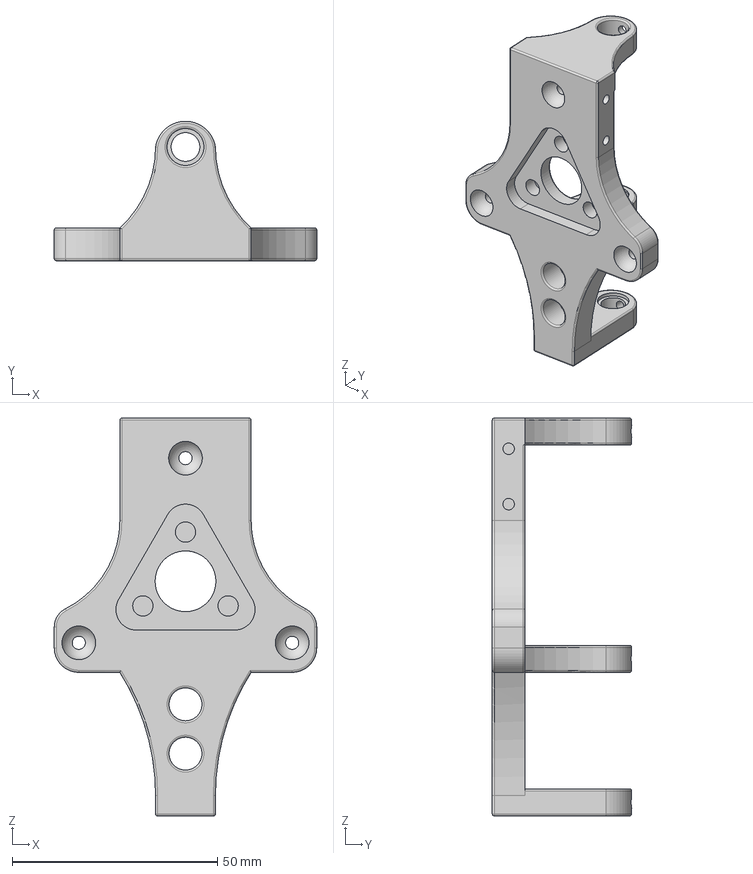
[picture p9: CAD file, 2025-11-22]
CAD/Spectrometer/Spectrometer_tool_base v5.step
64.0 x 34.0 x 97.0 mm

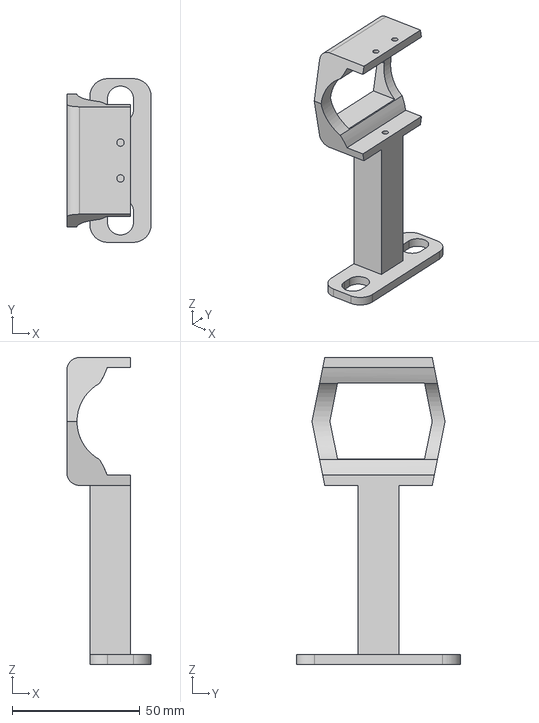
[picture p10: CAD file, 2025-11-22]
CAD/Vacuum_Gripper/vacuum_gripper v10.step
33.0 x 64.0 x 120.0 mm

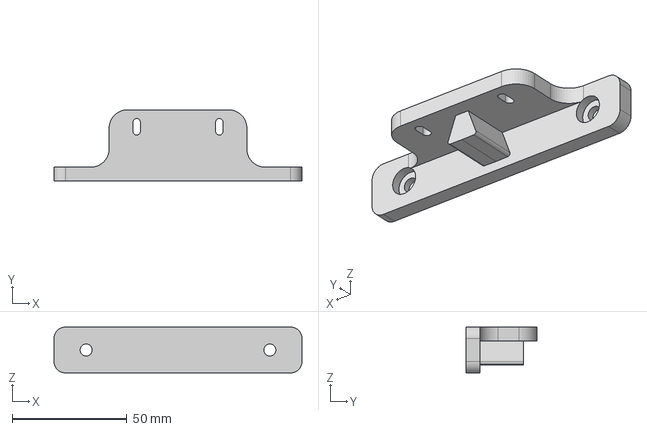
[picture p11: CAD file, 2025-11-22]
CAD/Dual_Syringe/tool_holder_parking_syringe_pump v5.step
108.0 x 31.1 x 20.0 mm

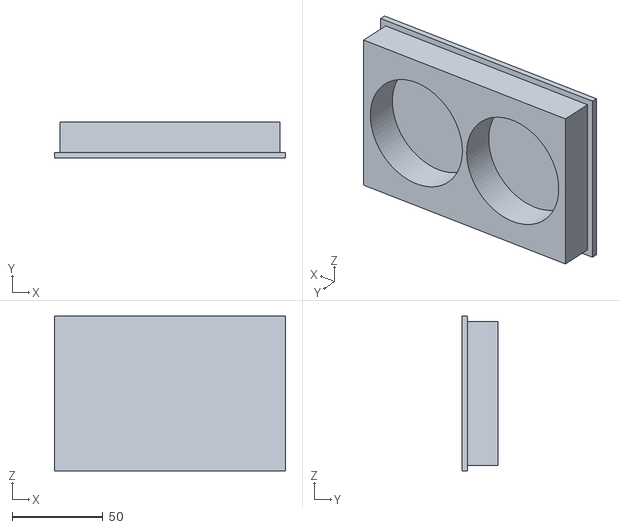
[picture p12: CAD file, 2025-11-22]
CAD/Labwares/UWSUNLAB_2_reservoir_container_60ml v1.stl
127.5 x 20.0 x 85.5

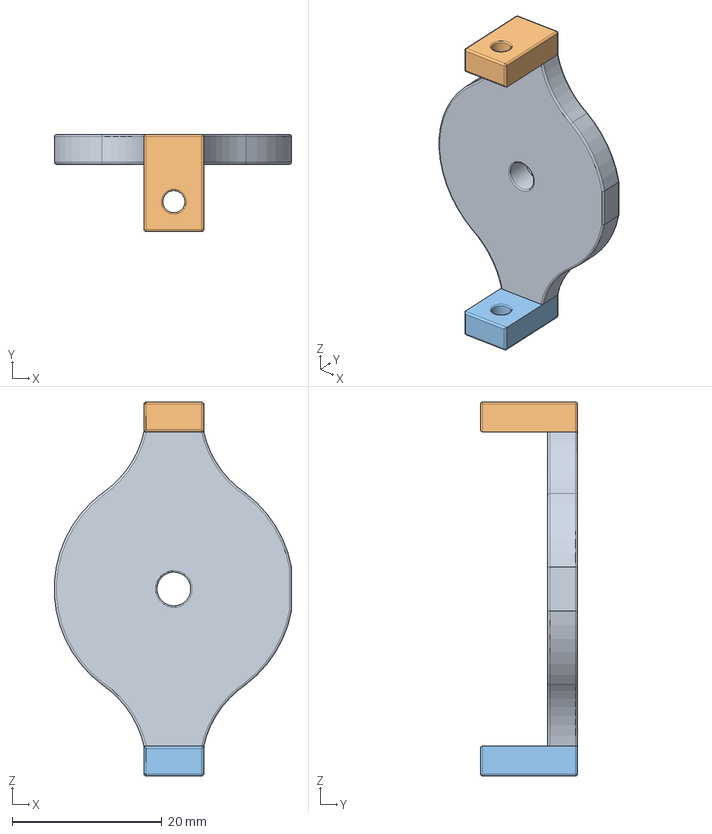
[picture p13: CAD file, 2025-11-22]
CAD/Vacuum_Gripper/vacuum_pump_cover v3.step
31.7 x 13.0 x 50.0 mm

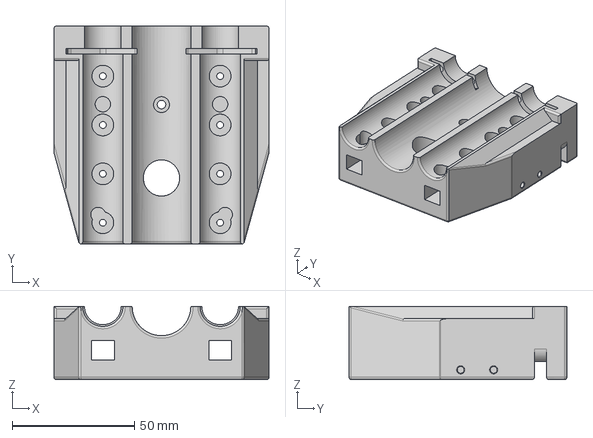
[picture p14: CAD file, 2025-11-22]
CAD/Dual_Syringe/double_syringe v15.step
88.0 x 89.2 x 30.0 mm

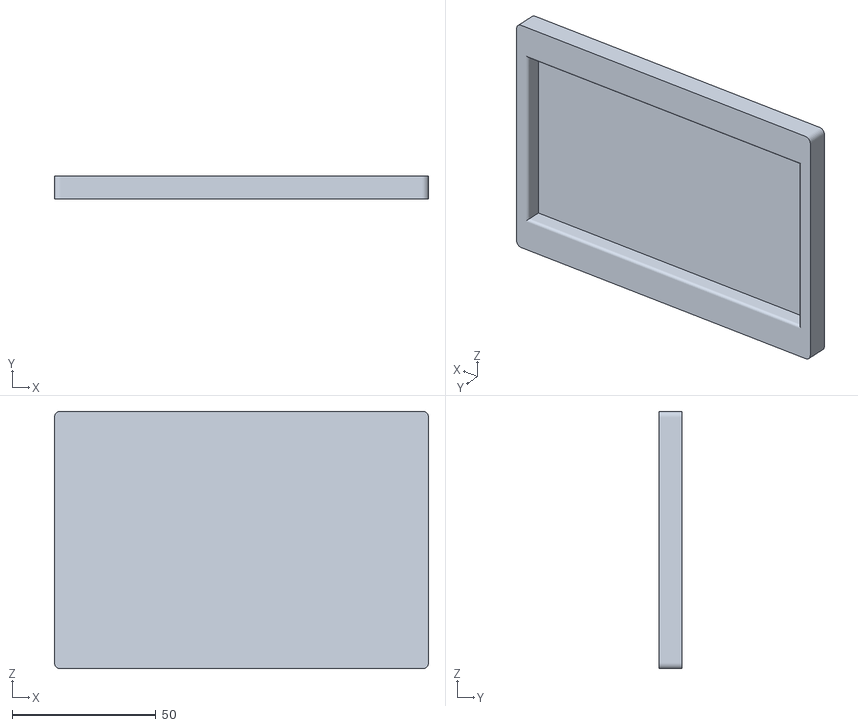
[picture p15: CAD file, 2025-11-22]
CAD/Labwares/UWSUNLAB_10WELLPLATE_LID v1.stl
130.0 x 8.00 x 89.5

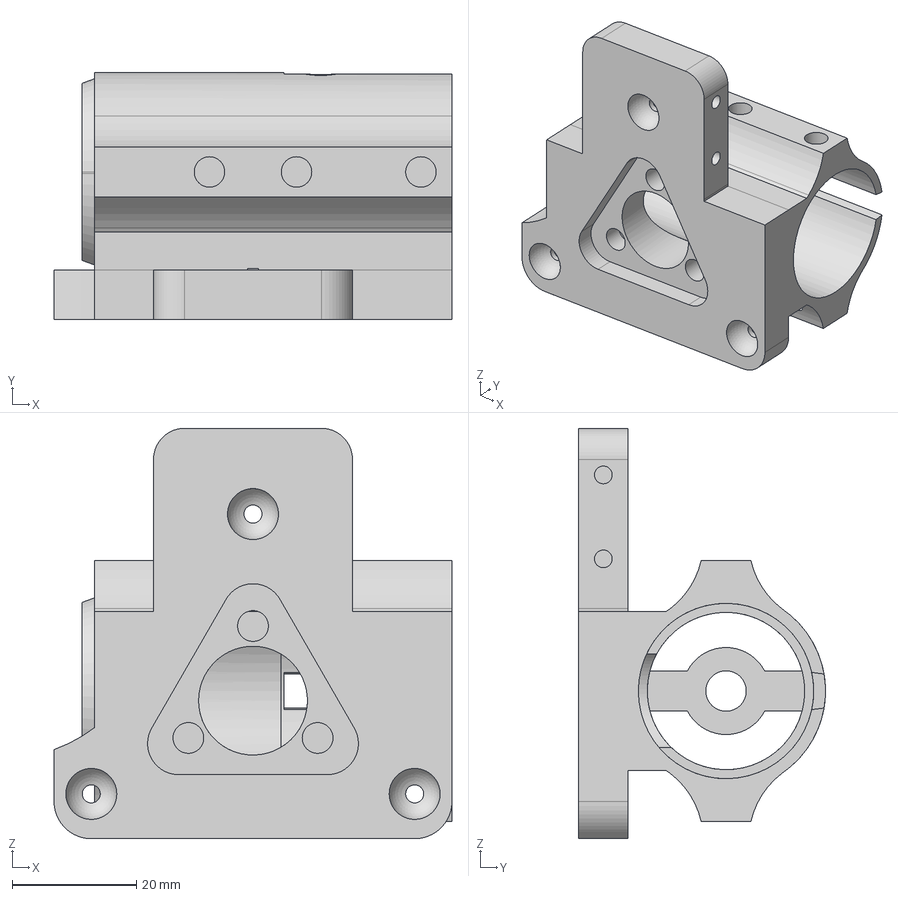
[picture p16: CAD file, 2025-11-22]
CAD/Vacuum_Gripper/vacuum_pump_holder v3.step
64.0 x 39.7 x 66.0 mm

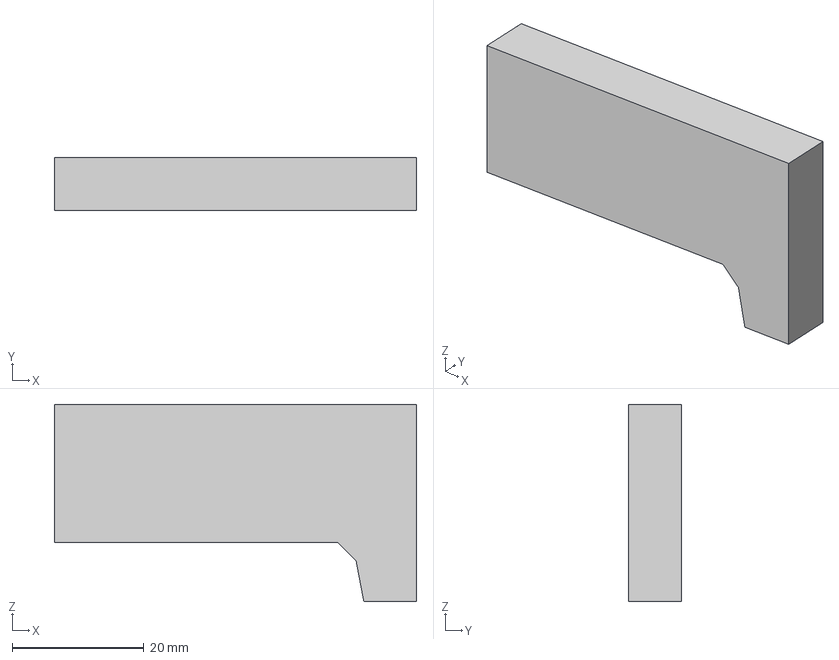
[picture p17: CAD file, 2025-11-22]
CAD/Dual_Syringe/parking_wing_left v2.step
55.0 x 8.00 x 30.0 mm

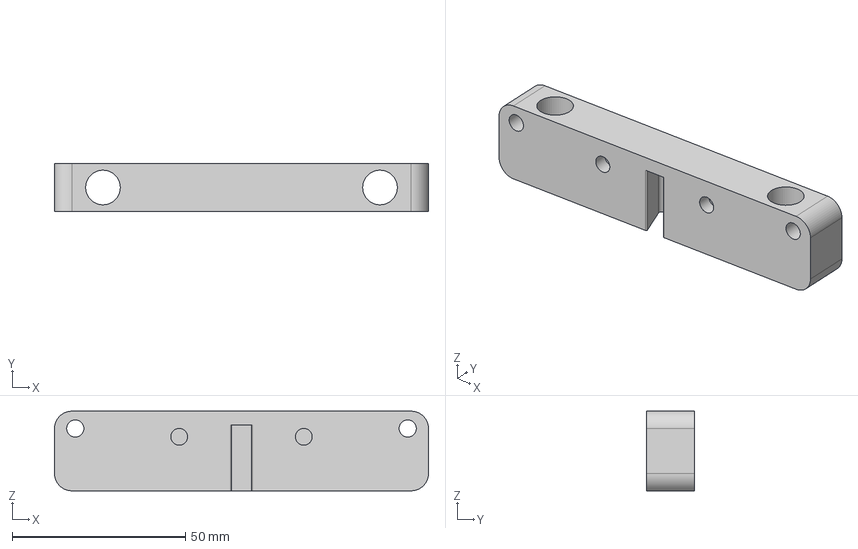
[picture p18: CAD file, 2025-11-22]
CAD/Dual_Syringe/tool_holder_double_syringe v8.step
108.0 x 14.0 x 23.0 mm

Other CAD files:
CAD/Dual_Syringe/double_syringe v15.f3d
CAD/Dual_Syringe/double_syringe v15.ipt
CAD/Dual_Syringe/double_syringe v15.stl
CAD/Dual_Syringe/parkin_wing_right v2.f3d
CAD/Dual_Syringe/parkin_wing_right v2.ipt
CAD/Dual_Syringe/parking_wing_left v2.f3d
CAD/Dual_Syringe/parking_wing_left v2.ipt
CAD/Dual_Syringe/tool_holder_double_syringe v8.f3d
CAD/Dual_Syringe/tool_holder_double_syringe v8.ipt
CAD/Dual_Syringe/tool_holder_parking_syringe_pump v5.f3d
CAD/Dual_Syringe/tool_holder_parking_syringe_pump v5.ipt
CAD/Spectrometer/Spectrometer_tool_base v5.f3d
CAD/Spectrometer/Spectrometer_tool_base v5.ipt
CAD/Vacuum_Gripper/vacuum_gripper v10.f3d
CAD/Vacuum_Gripper/vacuum_gripper v10.ipt
CAD/Vacuum_Gripper/vacuum_pump_cover v3.f3d
CAD/Vacuum_Gripper/vacuum_pump_cover v3.ipt
CAD/Vacuum_Gripper/vacuum_pump_holder v3.f3d
CAD/Vacuum_Gripper/vacuum_pump_holder v3.ipt

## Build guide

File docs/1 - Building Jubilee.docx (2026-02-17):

# Jubilee 3D Documentation (Part 1)

Prepared by: Arthur Chong

Date: 05/16/2025

This document is the first part of a multi-part guide that provides step-by-step instructions on how to build and connect a Jubilee 3D printer from scratch.

## Building Jubilee

### 1. Jubilee Project Wiki

The official Jubilee Project Wiki can be found at:
👉 https://jubilee3d.com/index.php?title=Main_Page
This site includes comprehensive information on:

- The overall design and philosophy of Jubilee
- Detailed build instructions
- Maintenance procedures and best practices

### 2. Purchase Information

The Jubilee motion platform kit used in the UW Sun Lab was purchased from:
🛒 https://www.filastruder.com/collections/jubilee/products/jubilee-motion-platform-kit

### 3. Inventory of Components

A full list of items included in the kit, as well as additional optional components sourced from other vendors (e.g., Amazon, Filastruder, etc.), can be found on GitHub:
📦 GitHub Items List (Items.md)
👉 https://github.com/uwsunlab/Axolotl_Jubilee/blob/main/Documentation/Building/Items.md

### 4. Jubilee Assembly

To begin assembling the Jubilee, refer to the official build instructions linked below. This step-by-step guide walks through the entire construction process, including subassemblies and grouped components:
🛠️ https://jubilee3d.com/index.php?title=Assembly_Instructions

If needed, refer to the image below for guidance on navigating to this page from the main Wiki.

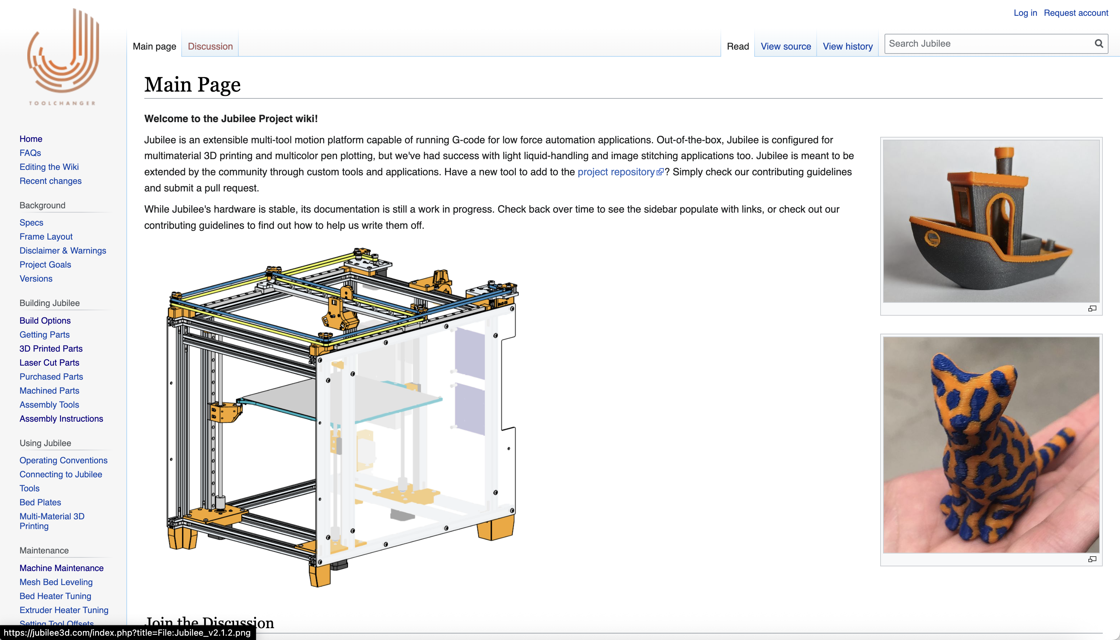
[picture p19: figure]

#### Grouped Assembly Sections

The Jubilee Assembly page is divided into multiple sections, each focusing on a specific part of the machine:

##### SECTION 1

- Outer Frame Assembly and Alignment
- Aluminum Motor Plate Assembly
- Double Pulley Corner Plate Assembly
- Aluminum Crossbar Assembly
- Toolchanger Remote Elastic Lock Assembly
- Toolchanger Carriage Assembly
- Magnetic Build Plate Assembly
- Duet2 Electronics Panel Assembly

##### SECTION 2

- Lower Frame Assembly
- CoreXY Frame Assembly

##### SECTION 3

- Z Axis Assembly

#### Additional Build Notes

We have also compiled additional notes that may help streamline the building process. These include clarifications, tips, and lessons learned from our build experience:

📝 Notes for Building Jubilee (PDF) (https://github.com/uwsunlab/Axolotl_Jubilee/blob/main/Documentation/Building/Notes%20for%20Building%20Jubilee.pdf)

### 5. Electronics

In the official Jubilee Assembly Instructions (https://jubilee3d.com/index.php?title=Assembly_Instructions), there is a dedicated section on electronics. This section explains how to properly connect the wiring behind the Jubilee before powering on the machine.

⚠️ Important: The wiring instructions depend on the type of control boards you are using. Please follow the specific wiring diagram provided on the website that corresponds to your hardware configuration.

#### Control Board Used in UW Sun Lab

For the UW Sun Lab setup, we used the following configuration:

- Duet 3 Mini + 3HC Expansion Wiring

The corresponding wiring diagram from the official Jubilee documentation is shown below:

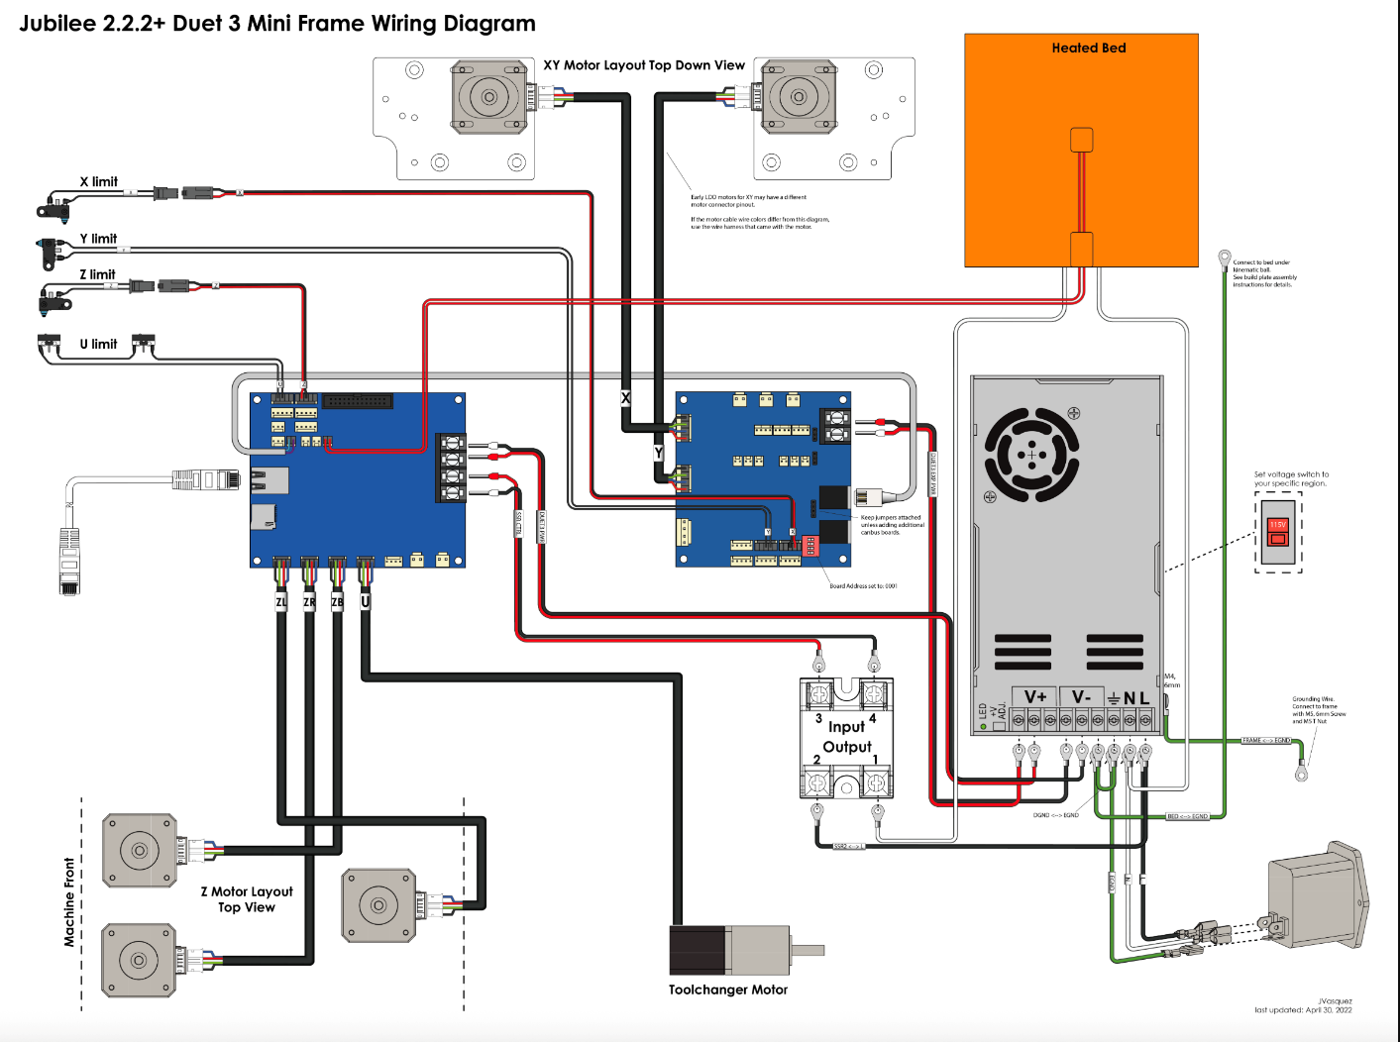
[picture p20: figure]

#### Axolotl (Our Jubilee) Wiring Reference

The figure below shows the custom wiring setup used in the Axolotl system within our lab. This image may help visualize wire routing, board positioning, and component connectivity during the assembly process:

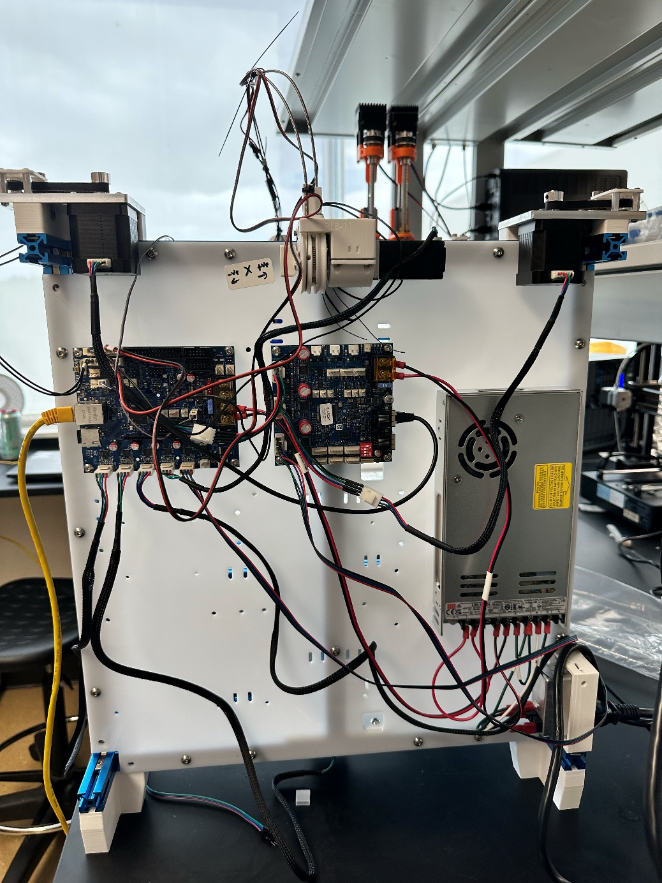
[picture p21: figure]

### 6. Customizable Jubilee

This section outlines the various tools that can be attached to the Jubilee 3D printer frame for experimental or automation purposes.

The Science Jubilee website is a valuable resource that provides information on using Jubilee for lab automation tasks. It includes a dedicated page—Building Science Jubilee Tools—which lists supported tools that are compatible with the Jubilee system.

🔗 Science Jubilee – Building Tools Page (https://science-jubilee.readthedocs.io/en/latest/building/building_tools.html)

#### Common Tools Used in Science Jubilee:

- Pipette Tool
- Inoculation Loop Tool
- Camera Tool
- Side Camera Tool
- HTTP Syringe Tool
- Lab Automation Deck

These tools are designed to integrate seamlessly with the Jubilee motion platform for automated laboratory workflows.

#### Designing Custom Tools

Users can also design and attach custom tools to the Jubilee frame to suit specific experimental needs.

To learn how to design your own tools, refer to the following page:
🛠️ Designing Custom Tools (https://science-jubilee.readthedocs.io/en/latest/building/designing_custom_tools.html)

#### Tool Pick-Up Requirements

After designing and mounting your custom tool, you must define its exact location so Jubilee can accurately pick it up during operation.

For instructions on setting tool positions and prerequisites, refer to:
📍 Tool Postrequisites (https://science-jubilee.readthedocs.io/en/latest/building/tool_postreqs.html)

## Connecting Jubilee

### 1. Installation Prerequisites

Before connecting to the Jubilee, ensure that all necessary files and dependencies are installed on your system. Follow the step-by-step installation guide provided by the Science Jubilee documentation:

🔧 Installation Instructions
👉 https://science-jubilee.readthedocs.io/en/latest/getting_started/installation.html

### 2. Setting Up an IP Address

To initialize communication with Jubilee, you must connect the machine via an Ethernet cable and assign a fixed IP address.

Jubilee provides detailed instructions on how to configure this connection properly. This step is essential to ensure the control board is accessible over your local network.

🌐 Connecting to Jubilee
👉 https://jubilee3d.com/index.php?title=Connecting_to_Jubilee

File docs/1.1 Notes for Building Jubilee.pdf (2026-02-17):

Jubilee Assembly Notes

Authors: Kai Xiang (Arthur) Chong
Date: 09/18/2024
UW Sun Lab

Images in the doc is from this link: Jubilee Assembly Instructions Manual (https://jubilee3d.com/index.php?title=Assembly_Instructions)

Additional Tools/Items Needed (Not Provided in the Kit):
1. General Purpose Lubricant (e.g., WD-40)
2. Soldering Iron (for heat inserts)
3. Tool Box with Hammer or Hydraulic Benchtop Press
4. Larger Bar Clamps (24-inch recommended)
5. Filaments for additional 3D printing
6. Ruler and/or Calipers

Important Notes:
1. 3D-Printed Parts Identification: Most 3D-printed parts have ID codes (e.g., BBC-04 or LBC-04). Ensure all parts are included in the kit to avoid needing additional 3D printing.
2. Fit Issues in 3D-Printed Parts: The holes of the 3D-printed parts may be too large or too small. Additionally, repeated screwing and unscrewing can loosen the holes. If you have access to a 3D printer, consider printing a replacement part when needed.
3. Heat Set Inserts: A heat set insert tool, purchased separately (e.g., from Filastruder), is required for easily inserting heat inserts into the holes of the 3D-printed parts.
4. Screws: The provided screws are in exact quantities. Do not lose any, as replacements may not be provided.
5. Components Overview: See "Items.md" (https://github.com/uwsunlab/Axolotl_Jubilee/blob/main/Documentation/Building/Items.md) for a visual representation of all components provided in the kit.

Section 1
Outer Frame Assembly:
- Clamps: Larger adjustable bar clamps (24-inch recommended) are required. The two smaller clamps provided in the kit are insufficient for this step (refer to Sheet 2 of 28).
- Lubrication: Lubricate the corner brackets with general-purpose lubricant (e.g., WD-40) to facilitate easy insertion into the 2020 extrusions (Sheet 3 of 28).

Aluminum Motor Plate Assembly:
- Y-Axis Limit Switch: Attach the Y-axis limit switch with its harness to RMS-05 (Sheet 2 of 11).

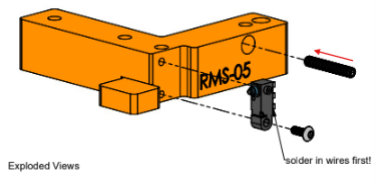
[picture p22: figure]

Image from Motor Plate Assembly Instruction.

[1]

- Set Screw Orientation: Ensure the head of the set screw faces outward during installation (Sheet 3 of 11).

Double Pulley Corner Plate Assembly:
- Gates Brand Pulleys: Follow the assembly instructions specific to the Gates brand pulleys. Skip Sheet 2 of 7 and Sheet 5 of 7.
- Screw Installation: Press fit the M3 button-head screw (8mm) and the M4 shoulder screw (25mm) into the corner pulley reinforcement plate (Sheet 3 of 7 and Sheet 6 of 7).

Remote Elastic Lock Assembly:
●

Aluminum Crossbar Assembly:
- Gates Brand Pulleys: Follow the Gates brand pulley instructions. Skip Sheet 2 of 8 and Sheet 5 of 8.
- Screw Installation: Press fit the M3 button-head screw (8mm) and the M4 shoulder screw (25mm) into the crossbar pulley reinforcement plate (Sheet 3 of 8 and Sheet 5 of 8).

Toolchanger Carriage Assembly:
- Pin Insertion: The Pin Insertion Fixture is not provided, so you'll need to hold the part by hand or use a clamp.
- M4 Dowel Pins: Insert the M4 dowel pins into the carriage front plate by carefully hammering them in or pressing them with a hydraulic press. Pre-drilling the dowel pin holes was not necessary.
- X-Axis Limit Switch: Attach the X-axis limit switch to CBP-05 (Sheet 6 of 7).

- Z-Axis Limit Switch: Attach the Z-axis limit switch to the carriage center plate (Sheet 7 of 7).

Build Plate Assembly:
- Magnetic Sheet: Do not attach the magnetic sheet to the top if you're not using it for 3D printing (Sheet 2 of 13).
- Heating Pad: We are not using the heating pad. Skip Sheet 6 of 13 and Sheets 10–12 of 13.

Duet 2 Electronics Panel Assembly:
- Back Panel Holes: The holes shown in the figure do not match those on the provided back panel. The necessary holes are present on the back panel, so insert screws as instructed by the diagram in the assembly instructions.
Please arrange it in the following arrangement

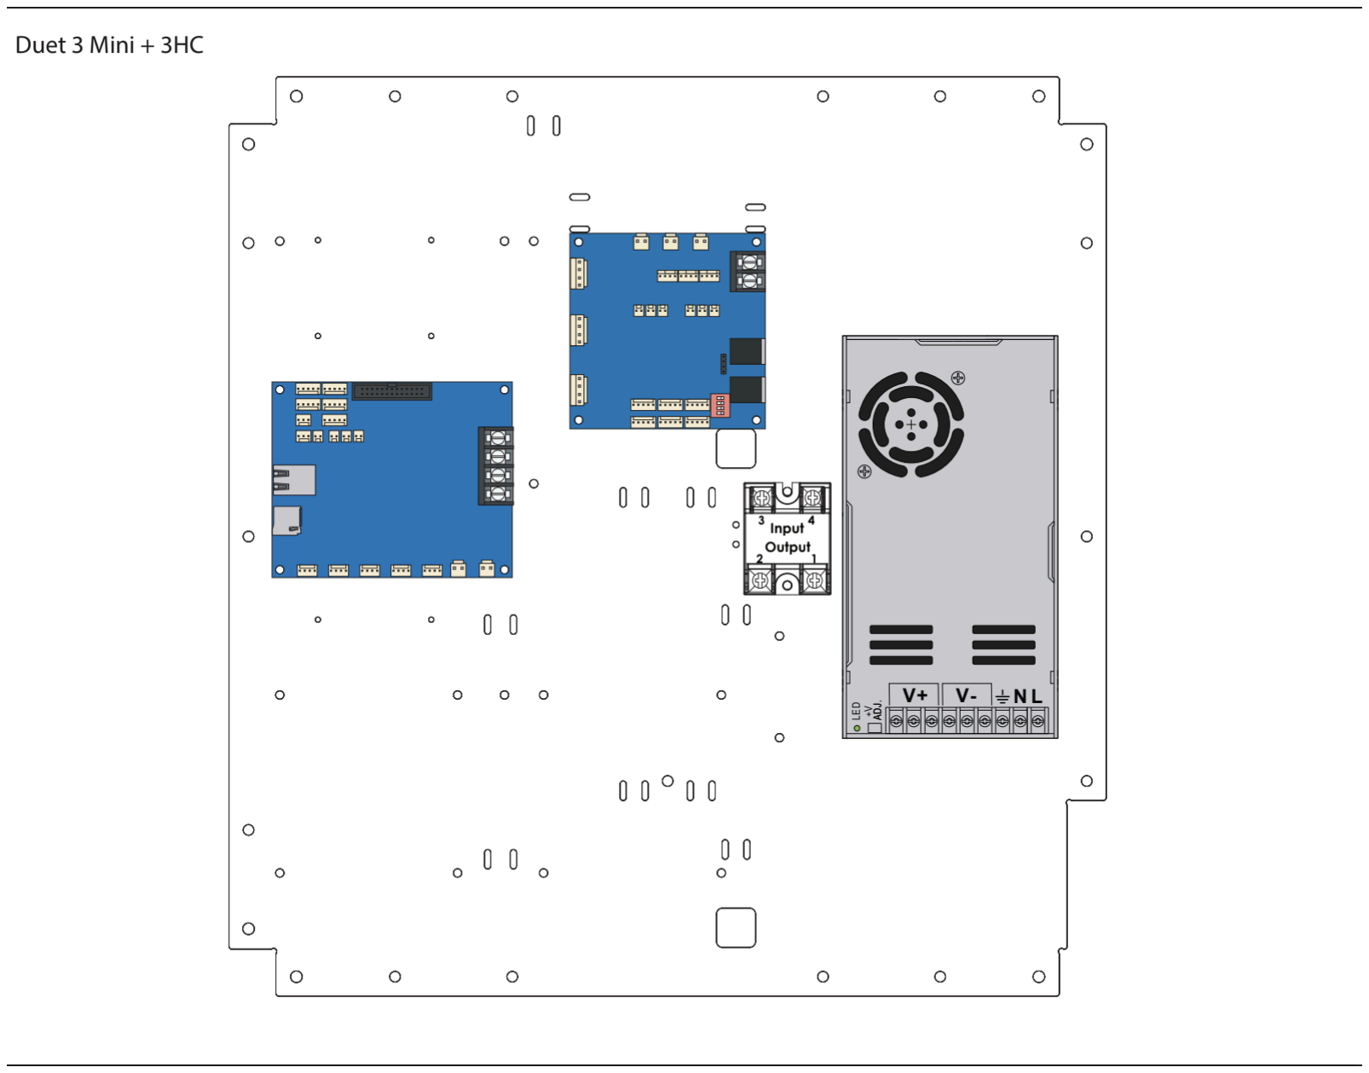
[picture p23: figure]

Image from Duet 2 Layout

[2]

Section 2
Lower Frame Assembly:
- Wire Direction: Ensure that the wire sticks out in the direction specified in the diagram (Sheets 4–6 of 10).
- Back Plate Positioning: The back plates must be positioned exactly in the middle of the rails with a tolerance of ± 0.2 mm (Sheet 8 of 10).

XY Frame Assembly:
- Hex Nut Handling: It is difficult to hold the hex nut while screwing the carriage center assembly with the crossbar assembly. Use an M3 Hex Nut Driver to securely hold the nut in place before screwing (Sheet 4 of 18).
- Pulley Alignment: Ensure that the Left Corner Pulley Assembly is aligned in a straight line with the Left Motor Plate Assembly. Similarly, ensure that the Right Corner Pulley Assembly is aligned with the Right Motor Plate Assembly (Sheet 9 of 18).

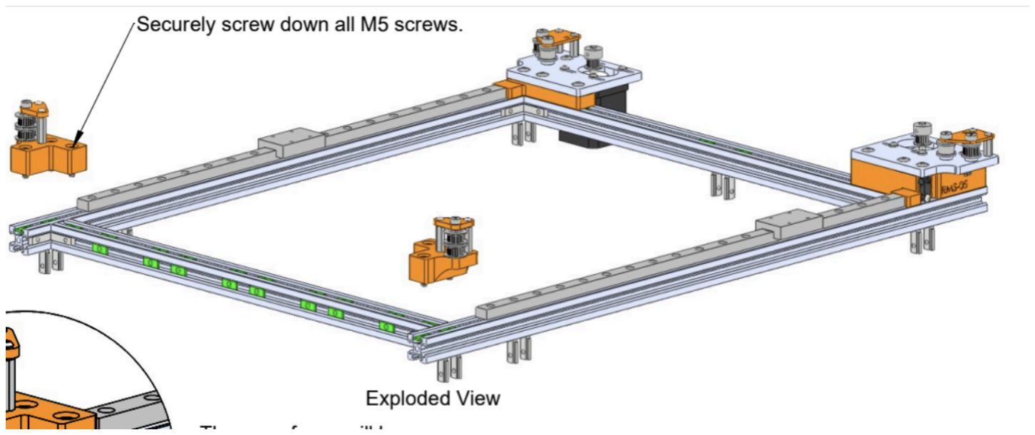
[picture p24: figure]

Image from XY Frame Assembly Instruction.

[3]

- Crossbar Assembly: When installing the crossbar assembly with the carriage center onto the CoreXY Frame Assembly, ensure that the crossbar is straight before securing it with fasteners (Sheet 10 of 18).

Section 3
Z Axis Assembly:
- Aluminum Z Yokes: If using the Jubilee Aluminum Z Yokes by Mandala Rose Works, skip Sheets 3-4 of 23 and Sheet 8 of 23.
- Assembly Procedure: Follow the same procedure as the Front Z Tower Assembly, but substitute the coupler assembly with the Aluminum Z Yokes (Refer to Sheets 9-12 of 23).

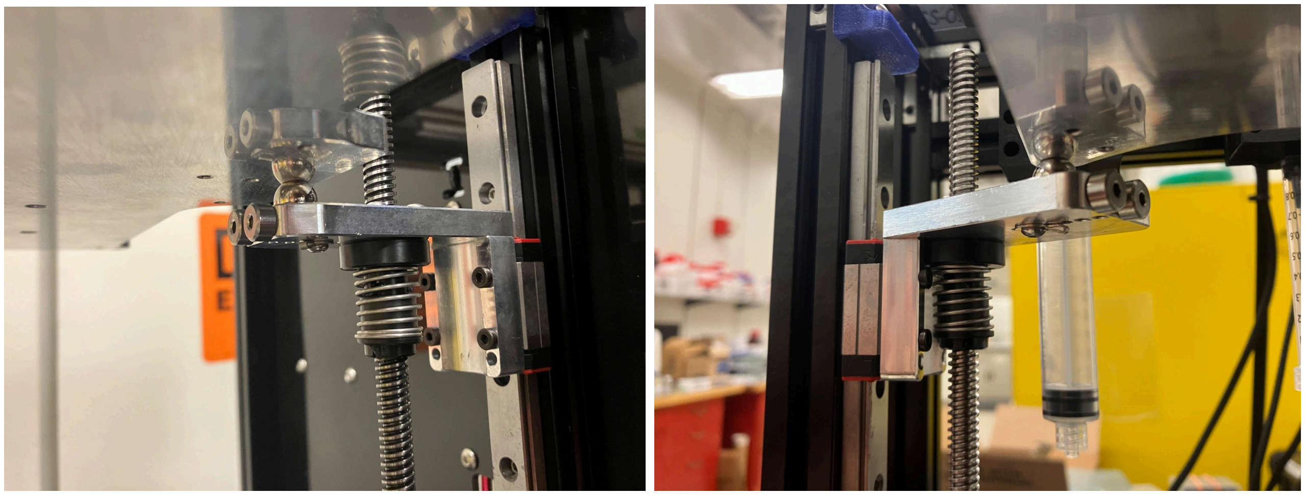
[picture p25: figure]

Aluminum Z Yokes Attachment on the rails and the bed plate.

- Bed Plate Attachment: Attach the bed plate onto the Aluminum Z Yokes using a zip tie to secure its position (Sheet 23 of 23).

Wiring Documentation:

- Duet3 Mini Frame Wiring Harnesses (https://github.com/machineagency/jubilee/blob/main/frame/assembly_instructions/wiring/duet3_mini/duet3_mini_wiring_consolidated.pdf)

Duet 3 Mini Frame Wiring Diagram

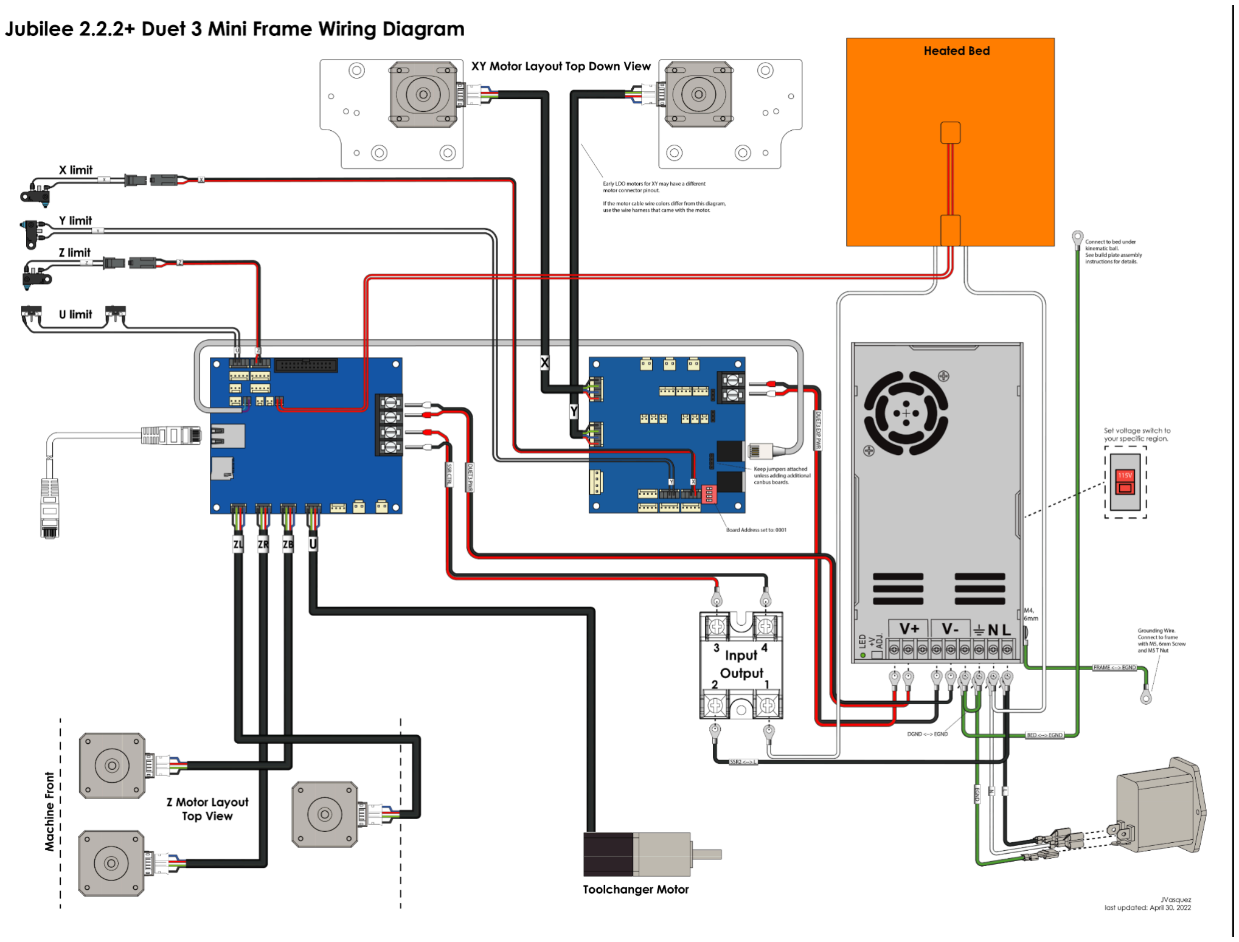
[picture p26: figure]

Image from Duet 3 Mini Frame Wiring Diagram.

[4]

- Please ensure that you insert the provided fuse into the PSU socket, as illustrated in the picture below, before turning Jubilee on.

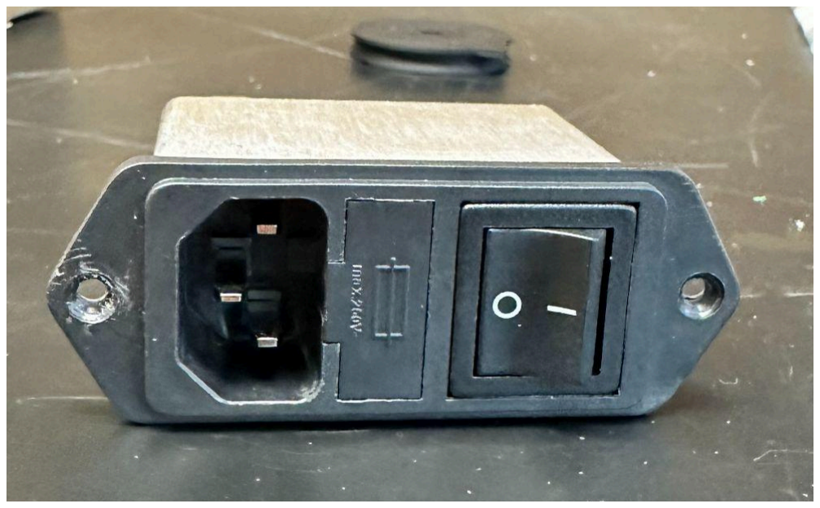
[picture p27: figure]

Horizontal View of the PSU Socket.

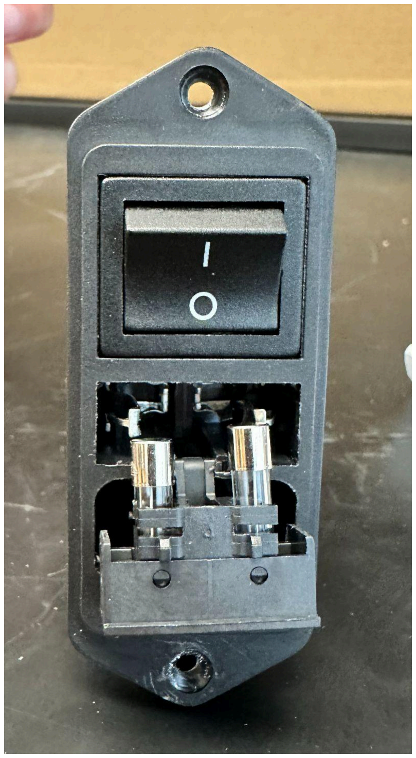
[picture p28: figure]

Vertical View View of the PSU Socket + Two Fuses

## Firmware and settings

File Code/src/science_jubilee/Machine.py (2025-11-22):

"""Driver for Controlling Jubilee"""

# import websocket # for reading the machine model

import json
import os
import time
import warnings
from functools import wraps
from pathlib import Path
from typing import Union

import requests  # for issuing commands
from requests.adapters import HTTPAdapter, Retry

from science_jubilee.decks.Deck import Deck
from science_jubilee.tools.Tool import Tool

# TODO: Figure out how to print error messages from the Duet.


# copied from machine agency version, may not be needed here


def get_root_dir():
    """Return the path to the duckbot directory."""
    return Path(__file__).parent.parent


##########################################
#               ERRORS
##########################################
class MachineConfigurationError(Exception):
    """Raise this error if there is something wrong with how the machine is configured"""

    pass


class MachineStateError(Exception):
    """Raise this error if the machine is in the wrong state to perform the requested action."""

    pass


##########################################
#               DECORATORS
##########################################
def machine_homed(func):
    """Decorator used to check if the machine is homed before performing certain actions."""

    def homing_check(self, *args, **kwds):
        # Check the cached value if one exists.
        if self.simulated:
            return func(self, *args, **kwds)
        if self.axes_homed and all(self.axes_homed):
            return func(self, *args, **kwds)
        # Request homing status from the object model if not known.
        self.axes_homed = json.loads(self.gcode('M409 K"move.axes[].homed"'))["result"]
        if not all(self.axes_homed):
            raise MachineStateError("Error: machine must first be homed.")
        return func(self, *args, **kwds)

    return homing_check


def requires_deck(func):
    """Decorator used ot check if a deck has been configured before performing certain actions."""

    def deck_check(self, *args, **kwds):
        if self.deck is None:
            raise MachineStateError("Error: No deck is set up")
        return func(self, *args, **kwds)

    return deck_check


def requires_safe_z(func):
    """Decorator used to ensure the deck is at a safe height before performing certain actions."""

    def z_check(self, *args, **kwds):
        current_z = float(self.get_position()["Z"])
        if self.deck:
            safe_z = self.deck.safe_z
        else:
            safe_z = 0
            # warnings.warn(f"No deck configured, safe z height has been set to {safe_z}. Please modify this if needed.")
        if current_z < safe_z:
            self.move_to(z=safe_z + 20)
        return func(self, *args, **kwds)

    return z_check


##########################################
#             MACHINE CLASS
##########################################


class Machine:
    """A class representation of Jubilee used to send  motion commands and polling the machine state."""

    # TODO: Set this up so that a keyboard interrupt leaves the machine in a safe state - ie tool offsets correct. I had an issue
    # where I keyboard interrupted during pipette tip pickup - tip was picked up but offset was not applied, crashing machine on next move. This should not be possible.

    LOCALHOST = "192.168.1.2"

    def __init__(
        self,
        port: str = None,
        baudrate: int = 115200,
        address: str = None,
        deck_config: str = None,
        simulated: bool = False,
    ):
        """Initialize the Machine object.

        :param port: The port to connect to the machine over serial, defaults to None
        :type port: str, optional
        :param baudrate: The baudrate to use when connecting to the machine, defaults to 115200
        :type baudrate: int, optional
        :param address: The IP address of the machine. This should match what is loaded onto the config.g on the Jubilee Duet's main board, defaults to None
        :type address: str, optional
        :param deck_config: The name of the deck configuration file to load, defaults to None
        :type deck_config: str, optional
        :param simulated: Whether to simulate the machine, defaults to False
        :type simulated: bool, optional

        :raises MachineStateError: If the machine is not in the correct state to perform the requested action. This is a user error, not a machine error.
        :raises MachineConfigurationError: If the machine does nto support the indicated configuration, e.g., a tool index is already in use.
        :raises ValueError: If Jubilee returns an invalid value, e.g., the axis limit queried is not correct or query is unsuccessful.

        """
        if address != self.__class__.LOCALHOST:
            print(
                "Warning: disconnecting this application from the network will halt connection to Jubilee."
            )
        # Machine Specs

        # serial info
        self.ser = None
        self.port = port
        self.baudrate = baudrate
        self.lineEnding = "\n"  # serial stuff

        # HTTP info
        self.address = address

        # self.debug = debug
        self.simulated = simulated
        self.model_update_timestamp = 0
        self.command_ws = None
        self.wake_time = None  # Next scheduled time that the update thread updates.

        self._absolute_positioning = True
        self._absolute_extrusion = (
            True  # Extrusion positioning is set separately from other axes
        )
        self._configured_axes = None
        self._configured_tools = None
        self._active_tool_index = None  # Cached value under the @property.
        self._tool_z_offsets = None  # Cached value under the @property.
        self._axis_limits = (None, None, None)  # Cached value under the @property.
        self.axes_homed = [
            False
        ] * 4  # We have at least X/Y/Z/U axes to home. Additional axes handled below in connect()
        self.deck = None
        # TODO: this is confusingly named
        self.tools = {}  # this is the list of available tools
        self.tool = None  # this is the current active tool
        self.current_well = None

        requests_session = requests.Session()
        retries = Retry(
            total=5, backoff_factor=0.1, status_forcelist=[500, 502, 503, 504]
        )

        requests_session.mount("http://", HTTPAdapter(max_retries=retries))
        self.session = requests_session

        if deck_config is not None:
            self.load_deck(deck_config)

        self.connect()

        self._set_absolute_positioning()  # force=True)

    def connect(self):
        """Connects to Jubilee over http.

        :raises MachineStateError: If the connection to the machine is unsuccessful.
        """
        # TODO: incorporate serial connection from machine agency version
        if self.simulated:
            return
        # Do the equivalent of a ping to see if the machine is up.
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

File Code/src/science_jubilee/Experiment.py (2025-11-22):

import json
import os
import string 
from dataclasses import dataclass 
from typing import Dict, Iterable, List, NamedTuple, Tuple, Union 

import time  
from datetime import datetime, timedelta 
import matplotlib.pyplot as plt
import pandas as pd 
import numpy as np

from science_jubilee.Machine import Machine
from science_jubilee.tools.Tool import Tool
from science_jubilee.decks.Deck import Deck
from science_jubilee.labware.Labware import Labware, Location, Well
from science_jubilee.tools.Double_Syringe import DoubleSyringe
from science_jubilee.tools.Syringe import Syringe
from science_jubilee.tools.Vacuum_Gripper import VacuumGripper 
from science_jubilee.tools.Oceandirect_axo import Spectrometer  


# Caution:[Done] While coding, keep in mind that sample_labware_sy/ssy/spec [vial_name] refer to different well objects. Hence when you apply any ops like dispense only the currentLiquidVolume paramter for that Well object will be updated. 
# Hence use only sample_labware_sy for all the single/dual syringe operations and in the spectromter operations use sample_labware_spec but update the sample_labware_sy Well object side-by-side. 

# TODO: [Done] Add the Lid handling code wherever needed with all the conditions. Do it for the record_spectrum and make_vial functions where we consider lids over the vials also and cover them after the op if completed. 
# TODO: [Done] Repair the problem with local and global copies of the self.samples2_sy (global labware class)-> sample_labware_sy(we make changes in well objects of it) -> self.samples2_sy(but the global labware class remains the same as before)
# TODO: Make the code more general and ask the user to tell where the well_number n slot_number where the precursors and solvents are kept. 

class Experiment:
    """
    A class to represent an experiment.
    """ 

    def __init__(self, machine: Machine, deck: Deck, all_tools: Dict[str, Tool], all_labwares: Dict[str, Dict[str, Labware]]):
        """
        Initialize an Experiment object. 
        :param machine: Machine object
        :type machine: Machine
        :param deck: Deck object
        :type deck: Deck
        :param all_tools: Dictionary of all tools
        :type all
        :param all_labwares: Dictionary of all labwares
        :type all_labwares: Dict[str, Dict[str, Labware]]
        """

        self.machine = machine
        self.deck = deck
        self.all_tools = all_tools
        self.all_labwares = all_labwares 

        self.init_expand() 

    
    def init_expand(self):
        """
        Function to initialise all the tools and labwares
        """ 

        # Tools
        self.single_syringe = self.all_tools["single_syringe"]
        self.dual_syringe = self.all_tools["dual_syringe"]
        self.gripper = self.all_tools["gripper"]
        self.spectrometer = self.all_tools["spectrometer"]

        # Labwares 
        self.slot1 = self.all_labwares["slot1"]
        self.slot2 = self.all_labwares["slot2"]
        self.slot3 = self.all_labwares["slot3"]
        self.slot4 = self.all_labwares["slot4"]
        self.slot5 = self.all_labwares["slot5"]

        self.precursors = self.slot1["precursors"]
        self.samples2_sy = self.slot2["samples2_sy"]
        self.samples2_ssy = self.slot2["samples2_ssy"]
        self.samples2_spec = self.slot2["samples2_spec"]
        self.solvents = self.slot3["solvents"]
        self.vacuum_location = self.slot4["vacuum_location"]
        self.samples5_sy = self.slot5["samples5_sy"]
        self.samples5_ssy = self.slot5["samples5_ssy"]
        self.samples5_spec = self.slot5["samples5_spec"]

        # some more variables
        self.need_spectrum_refs = True # Flag to check if the spectrum references are already present

        # save the log_file_path 
        log_dir = self.spectrometer.experiment_dir
        log_file = "operations_log.txt"
        os.makedirs(log_dir, exist_ok=True)

        # Full path to the log file
        self.log_path = os.path.join(log_dir, log_file)


    def make_batch(self, file_name: str) :
        """
        Function to create a batch of samples  
        :param file_name: Name of the Json file which contains the details of the samples to be synthesized
        :type file_name: str 

        Here the procedure of synthesis n spectrum recording is as follows:
        1. Fill dual syringe with precursors 
        2. Dispense metal_precursor in all the vials one-by-one  
        3. Apply make_vial on all the vials one-by-one 
            3.1 dispense organic precursor 
            3.2 mix the solution 
            3.3 Take T0 spectrum reading 
            3.4 wash the probe 
        4. Record spectrum readings at regular intervals for all the vials

        """ 
        axo = self.machine
        precursors = self.precursors
        solvents = self.solvents


        with open(file_name, "r") as f:
            self.data = json.load(f)

        # Extract data out of the json file 
        self.spectrum_record_interval_mins = self.data["spectrum_record_interval_mins"] 
        self.max_spectrum_records = self.data["max_spectrum_records"] 

        # Parse all the slot names from the json 
        self.slot_names = []
        for k in self.data.keys():
            k = k.lower().strip()
            if k[:4]=="slot":
                 self.slot_names.append(k) 

        # Save the vial recipes (optional)
        self.save_vial_recipes()  

        # Record the spectrometer reference spectrum if needed 
        if self.need_spectrum_refs:
            self.record_spectrum_refs() 
            self.need_spectrum_refs = False
        else: 
            pass 

        # Step 1. Dispense solvents in all the vials one-by-one
        self.dispense_solvent_all_vials() 

        # Step 2.Dispense metal_precursor in all the vials one-by-one
        self.dispense_metal_precursor_all_vials()


        # Loop over all the slots for step 3
        for slot_name in self.slot_names: 
            slot = int(slot_name[4:]) if slot_name[4:].isdigit() else slot_name[4:]

            all_vials = self.data[slot_name]    # a dict with "A1": {}, "A2": {} ...

            # Loop over all the vials in the slot
            for vial_name, vial_param in all_vials.items(): 
                metal_precursor_vol = vial_param["metal_precursor_vol"]
                organic_precursor_vol = vial_param["organic_precursor_vol"]
                solvent_vol = vial_param["solvent_vol"]
                
                # Step 3. Dispense the organic precursor -> mix the solution -> take T0 spectrum reading -> wash the probe
                self.make_vial(slot= slot, vial_name= vial_name, metal_precursor_vol= metal_precursor_vol, organic_precursor_vol= organic_precursor_vol, solvent_vol= solvent_vol) 
            
        # Reset the dual syringe 
        self.reset_dual_syringe()

        # Step 4. Record spectrum till the end of the experiment 
        self.record_spectrum_till_end()
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

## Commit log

2025-11-22 Add Dataset
    [A1.csv, A2.csv, A3.csv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]
2026-02-17 Update dataset
    [A1.csv, A2.csv, A3.csv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]
